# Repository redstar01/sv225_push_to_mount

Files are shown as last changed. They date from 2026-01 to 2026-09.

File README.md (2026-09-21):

# Проект модернизации альт-азимутальной монтировки телескопа Svbony sv225 до системы Push-To

🌐 **Русский** | [English](README.en.md)

DIY-проект: обычная ручная альт-азимутальная монтировка превращается в Push-To с привязкой к звёздам. ESP32 с двумя магнитными энкодерами MT6701 отдаёт положение осей в **Stellarium** (USB, протокол Meade LX200) или **SkySafari** (Bluetooth / Wi-Fi).

<p align="center">
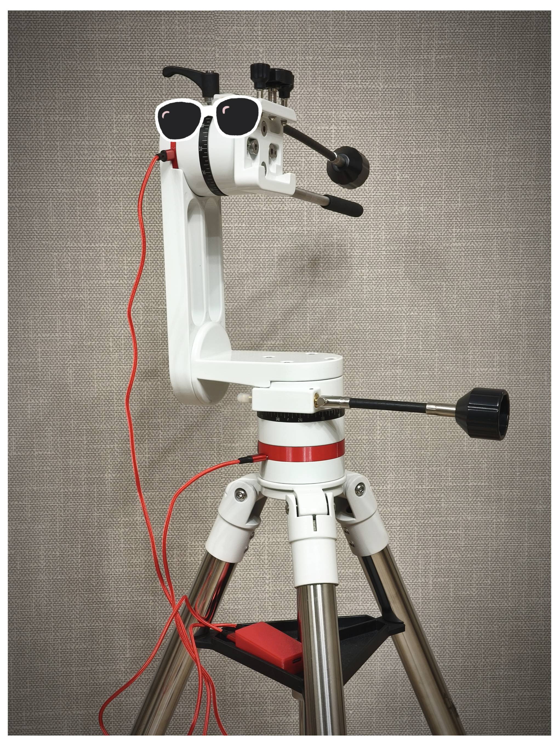
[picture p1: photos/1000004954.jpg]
    
</p>

## 🆕 Что нового: версия для Stellarium (beta)

Проект развивается в сторону **Stellarium** — эта версия уже приоритетная и рабочая (beta). Прошивки для SkySafari остаются стабильными и поддерживаются.

- **Подключение по USB** — не нужны Bluetooth, сопряжение и телефон: Stellarium видит ESP32 как монтировку Meade LX200.
- **Вся астрономия считается на ESP32** — звёздное время, прецессия J2000, перевод «углы осей ↔ RA/Dec».
- **Настройка с телефона по Wi-Fi** — страница `https://192.168.4.1/`: время UTC одной кнопкой, три слота места наблюдения с GPS, калибровка осей, живая таблица состояния.
- **Привязка к звёздам** (Sync из Stellarium) — до 6 точек, от 3 точек линейная модель по МНК; повторный Sync уточняет точку, а невязки и удаление — в веб-таблице.
- **Старт от полюса** — до первой привязки крест визирных нитей стоит у Полярной и следует за монтировкой.
- **Перевал через зенит** — координаты не «замирают»: прошивка отражает точку наведения, и крест продолжает двигаться.

<p align="center">
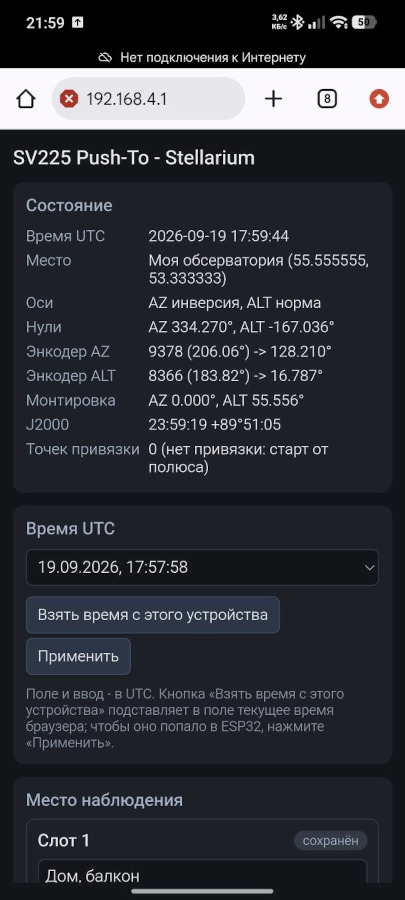
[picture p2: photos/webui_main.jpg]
    
    <br/>
    <em>Веб-интерфейс: состояние, время, слоты места и привязка — всё с телефона</em>
</p>

## 🚀 Обзор проекта

### Что такое Push-To?
Это система, которая показывает наблюдателю направление вращения ручек монтировки (после привязки к опорной звезде(-ам)), для наведения на любой звёздный объект.
Это значительно упрощает поиск тусклых галактик, туманностей и звёздных скоплений, невидимых невооруженным глазом.
А так же сильно помогает новичкам - астрономам для поиска объектов.

### Отличие от Go-To
В Go-To системе, монтировка сама наводится на объекты звездного неба за счет моторизированных приводов - это следующая ступень автоматизации и упрощения наведения.
В Push-To мы привязываемся к звездному небу и далее путем ручного вращения монтировки переходим от одной цели к другой, сопоставляя данные по наведению в программе-планетарии.

### Как это работает?
На осях монтировки устанавливаются датчики угла поворота (энкодеры).
Микроконтроллер ESP32 считывает их показания и передает данные в программу планетарий — та видит изменения положения осей и показывает, куда смотрит труба.
Для Stellarium пересчёт углов в координаты J2000 и модель привязки считаются прямо на ESP32.

## 📎 Функциональные возможности

### Stellarium — beta, приоритетное направление
- Протокол Meade LX200, подключение по USB (9600 8N1) — без Bluetooth и сопряжения.
- Координаты J2000; вся математика на ESP32: GMST/LST, прецессия (IAU 1976), alt-az ↔ RA/Dec.
- Привязка Sync: 1 точка — постоянные смещения, 2 — усреднение, 3+ — линейная модель (МНК), всего до 6 точек.
- Веб-интерфейс по Wi-Fi: время UTC, 3 слота места с названиями и GPS, калибровка осей (инверсия, нули), список привязок с невязками.
- Старт «от полюса» без привязки; перевал через зенит/надир не ломает наведение.
- Не нужны интернет и приложение на телефоне: USB-кабель и ПК со Stellarium.

### SkySafari — стабильные версии
- Протокол Basic Encoder System.
- Подключение по Bluetooth (удобно тем, что Wi-Fi остаётся свободным для интернета).
- Подключение по Wi-Fi (опционально, необходимо заливать отдельную прошивку).

## 💻 Программное обеспечение

Проект написан на C++/Arduino для платформы ESP32. Исходные коды [здесь](./src).

| Прошивка | Планетарий | Подключение | Статус |
|---|---|---|---|
| [stellarium_firmware.ino](./src/stellarium_firmware.ino) | Stellarium | USB (LX200) + веб-настройка по Wi-Fi | beta, приоритет |
| [bluetooth_firmware.ino](./src/bluetooth_firmware.ino) | SkySafari | Bluetooth | стабильно |
| [wifi_firmware.ino](./src/wifi_firmware.ino) | SkySafari | Wi-Fi | стабильно |

Инструкции: [подключение Stellarium](./tutorials/stellarium_connection.md) · [подключение SkySafari](./tutorials/skysafari_connection.md)

## 🎯 Как пользоваться

### Stellarium
Подробная инструкция — [tutorials/stellarium_connection.md](./tutorials/stellarium_connection.md).

1. Прошейте [stellarium_firmware.ino](./src/stellarium_firmware.ino): плата **ESP32 Dev Module**, схема разделов — стандартная (или «Huge APP (3MB No OTA/1MB SPIFFS)» для запаса).
2. Подключите ESP32 к ПК по USB. В Stellarium: плагин **Telescope Control** → «LX200 (compatible)» → «Послед. порт» → равноденствие **J2000**.
3. Задайте время и место: Wi-Fi **`redstar01`** (пароль `1234567890`) → `https://192.168.4.1/` (браузер один раз предупредит о самоподписанном сертификате). Кнопка «Взять время с этого устройства» → «Применить»; в слоте места — «Взять GPS» → «Использовать».
4. Наведите монтировку на звезду, выберите её в Stellarium и нажмите **`Ctrl+Shift+1`** (Sync). Повторите для 2–3 звёзд, разнесённых по небу.
5. Вращайте ручки — крест визирных нитей двигается по небу. Выберите объект и подводите трубу вручную.

До первой привязки крест стоит на полюсе мира (рядом с Полярной) и следует за монтировкой: первый Sync заменяет эту грубую модель точной.
Время и координаты должны совпадать со Stellarium: 1 минута расхождения времени — это 15′ промаха у небесного экватора.
Если веб-интерфейс недоступен, те же параметры задаются командами по serial: `T 2026-09-17 18:00:00`, `SLOT 1 55.0583 73.2950 Дача`, `SLOTUSE 1` (`HELP` — список команд).

### SkySafari
Подробная инструкция — [tutorials/skysafari_connection.md](./tutorials/skysafari_connection.md).

1. Подключаем питание через usb (для devkit платы) к esp 32.
2. Прошиваем `bluetooth_firmware.ino` (или `wifi_firmware.ino`) и на устройстве с SkySafari подключаемся к bluetooth(wifi) esp 32.
3. [В SkySafari делаем коннект к предварительно настроенному телескопу.](./tutorials/skysafari_connection.md) (число шагов энкодеров `-16383`).
4. Делаем привязку к опорным звездам, желательно от 3 шт, но сносно будет работать и по 1 звезде. (если поле зрения телескопа не велико, то искомый объект всегда попадет в окуляр).
5. Вращаем ручки монтировки, видим движение направления телескопа в SkySafari. Далее выбираем любой объект в программе и подводим телескоп к нужной цели.

## ⚙️ Компоненты и материалы
- Микроконтроллер ESP32 DevKit (1 шт)
- Абсолютные магнитные энкодеры MT6701 (2 шт)
- Увеличенные магниты для энкодеров (опционально, позволят увеличить точность) (2 шт)
- USB-C порты (4 шт) 
- Удлиненные болты в дюймовой системе, размер 1/4-20, длинна 1-1/8" (6 шт)
- Подшипник игольчатый 6*19 (2шт)
- Смазка ЦИАТИМ-F
- 3D печатные детали

## 🔧 Cборка
Подробная инструкция по сборке [здесь](./tutorials/assembly.md)

## 🖨️ 3D модели

Все модели для печати можно найти [здесь](./models/STL)

## 📷 Фото

Фото процесса сборки и конечный результат можно найти [здесь](./photos)

## 📞 Связаться с автором

GitHub: https://github.com/redstar01/sv225_push_to_mount

Telegram: https://t.me/redstar01 (Павел Красноперов)

## Отказ от ответственности
Вся информация предоставляется «как есть», без любых гарантий. Автор не несет ответственности за любой ущерб, повреждение оборудования, травмы или иные проблемы, возникшие в результате использования данной информации. Вы действуете на свой страх и риск.

## ❤️️ P.S. Если вам понравился проект, поставьте звезду на GitHub!

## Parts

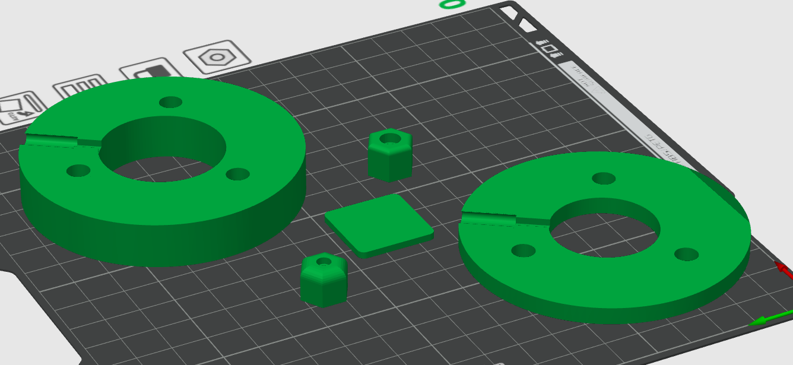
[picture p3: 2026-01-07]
models/STL/parts/preview.png

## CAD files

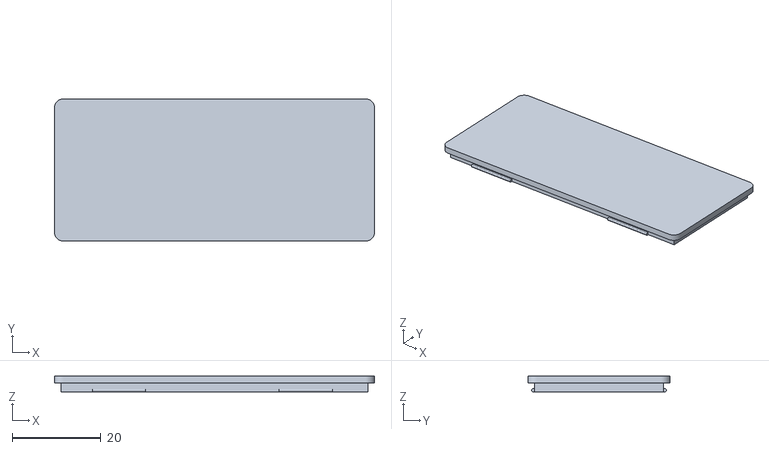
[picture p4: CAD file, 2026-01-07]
models/STL/body/body-top.stl
72.0 x 32.0 x 3.50

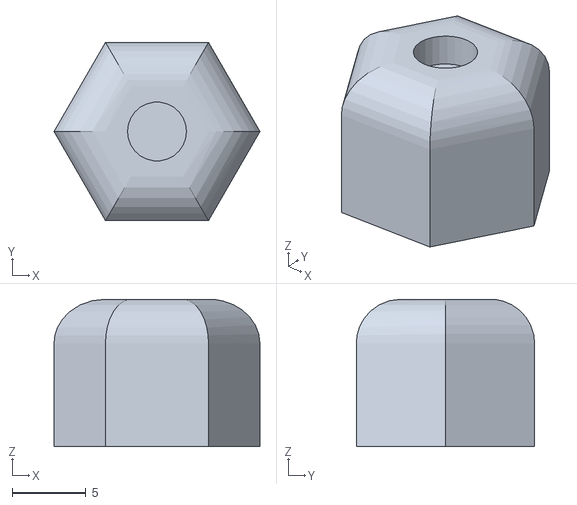
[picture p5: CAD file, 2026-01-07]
models/STL/parts/magnet_holder_default.stl.stl
14.0 x 12.1 x 10.0

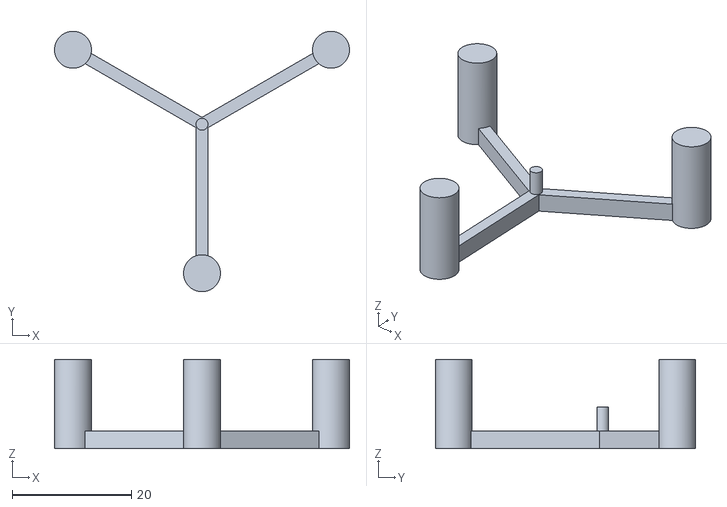
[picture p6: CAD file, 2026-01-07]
models/STL/pattern/template_for_mounting.stl
49.5 x 43.7 x 15.0

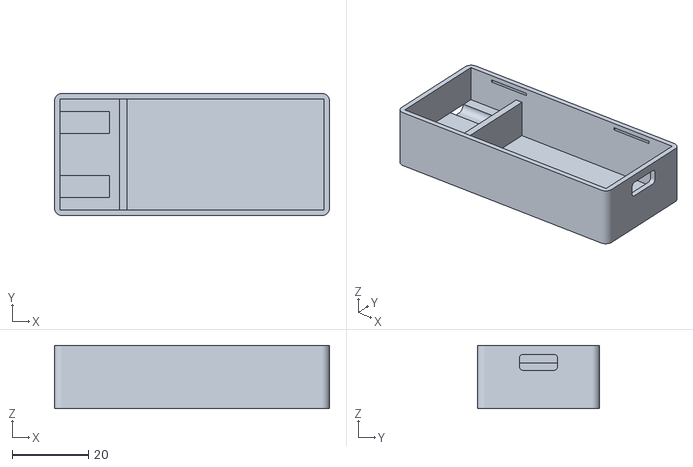
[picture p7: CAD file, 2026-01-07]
models/STL/body/body.stl
72.0 x 32.0 x 16.5

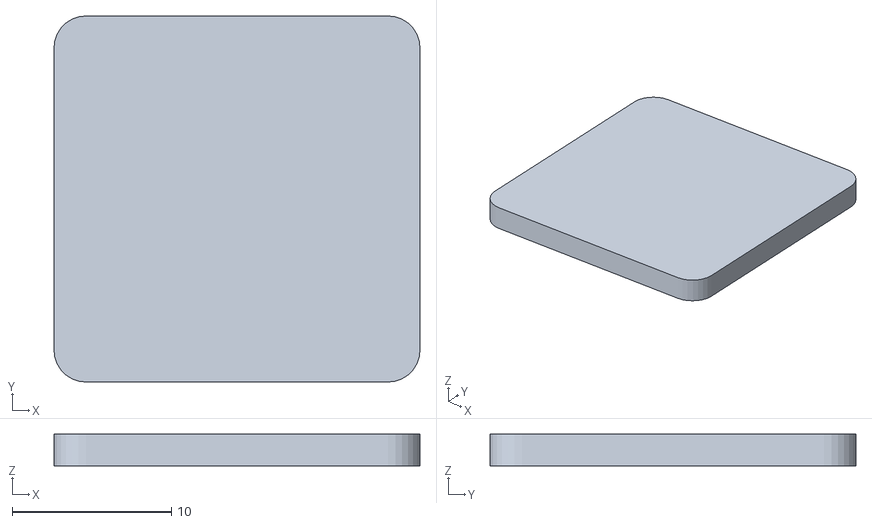
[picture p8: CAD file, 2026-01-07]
models/STL/parts/pcb_spacer_2mm.stl
23.0 x 23.0 x 2.00

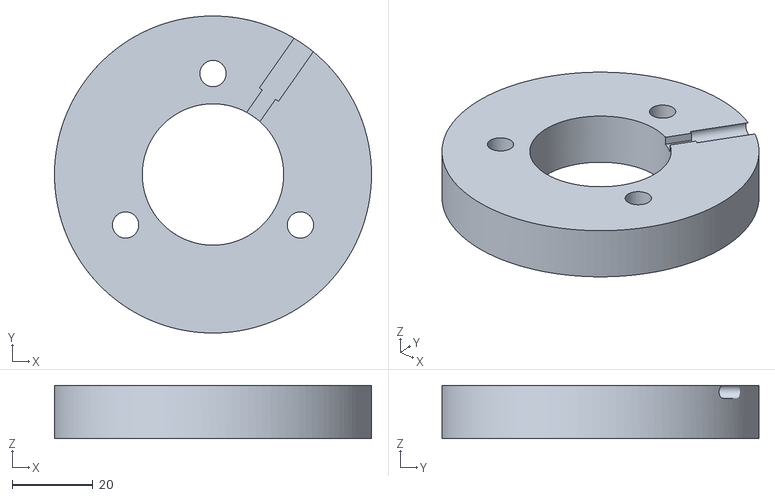
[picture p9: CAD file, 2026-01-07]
models/STL/parts/azm_spacer.stl.stl
78.5 x 78.5 x 13.2

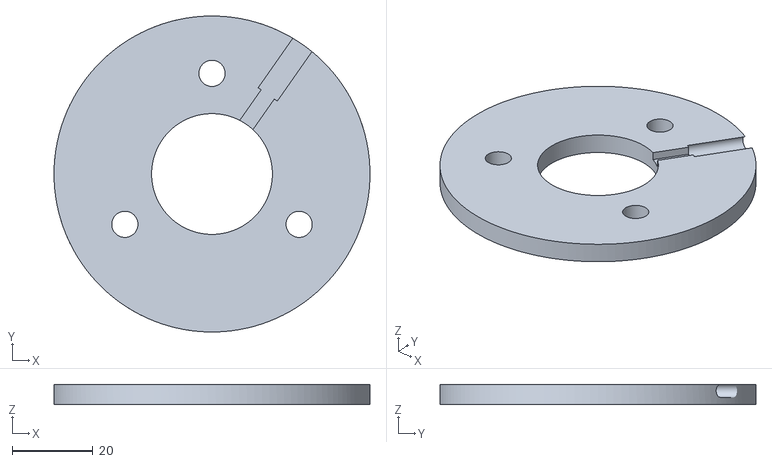
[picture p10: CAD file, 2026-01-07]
models/STL/parts/alt_spacer.stl
78.5 x 78.5 x 5.00

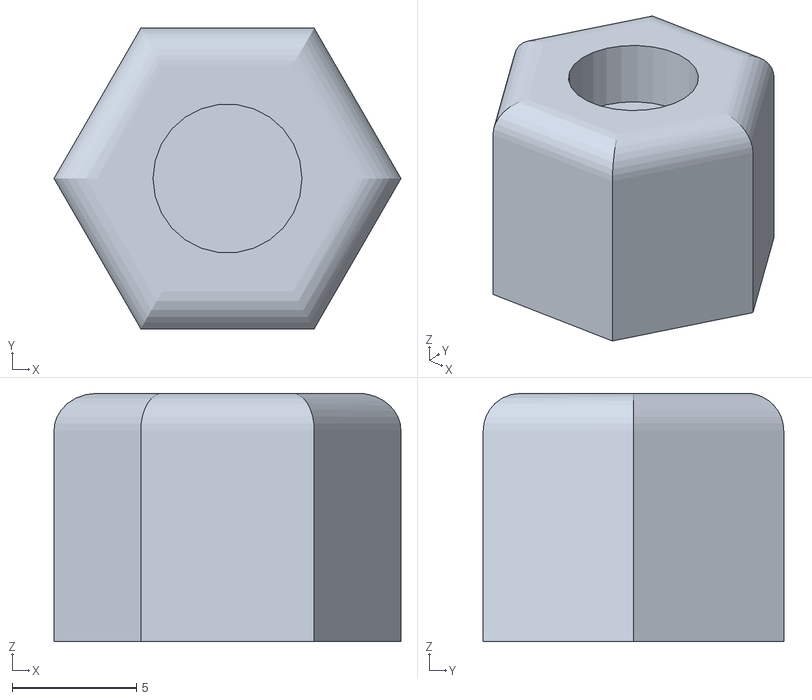
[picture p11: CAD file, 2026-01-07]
models/STL/parts/magnet_holder_big_6mm.stl
14.0 x 12.1 x 10.0

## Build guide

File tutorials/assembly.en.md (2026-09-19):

# Guide to upgrading the Svbony SV225 alt-azimuth mount to Push-To

🌐 [Русский](assembly.md) | **English**

## Preparatory work
Before upgrading the mount, its mechanics should be brought to the best possible condition; in my case I replaced the grease and got rid of the play by adding a thrust bearing.

### Grease replacement
Before assembly proper, the factory grease must be completely replaced, because from the factory it stiffens badly in the cold even at slightly below zero temperatures.
The recommended grease is CIATIM-F (ЦИАТИМ-Ф) — the cheapest of the analogs and it has no meaningful effect on the aluminum the mount is made of.

<div style="text-align: center;">
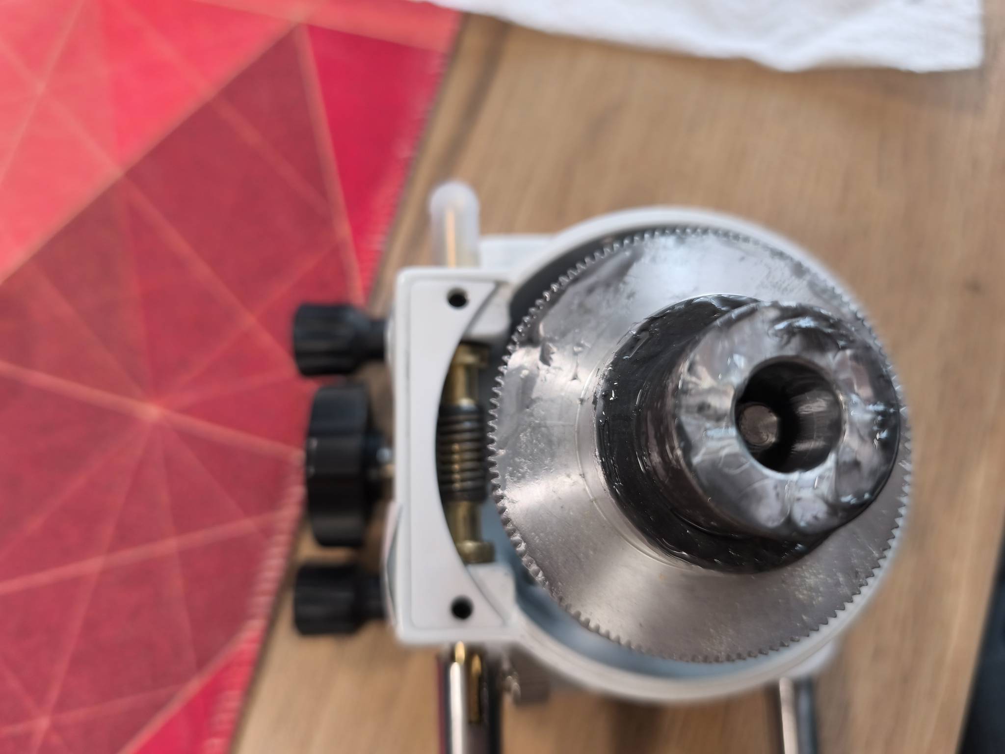
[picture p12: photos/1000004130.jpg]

<p><em>Removing the old silicone-based grease:</em></p>
</div>

<div style="text-align: center;">
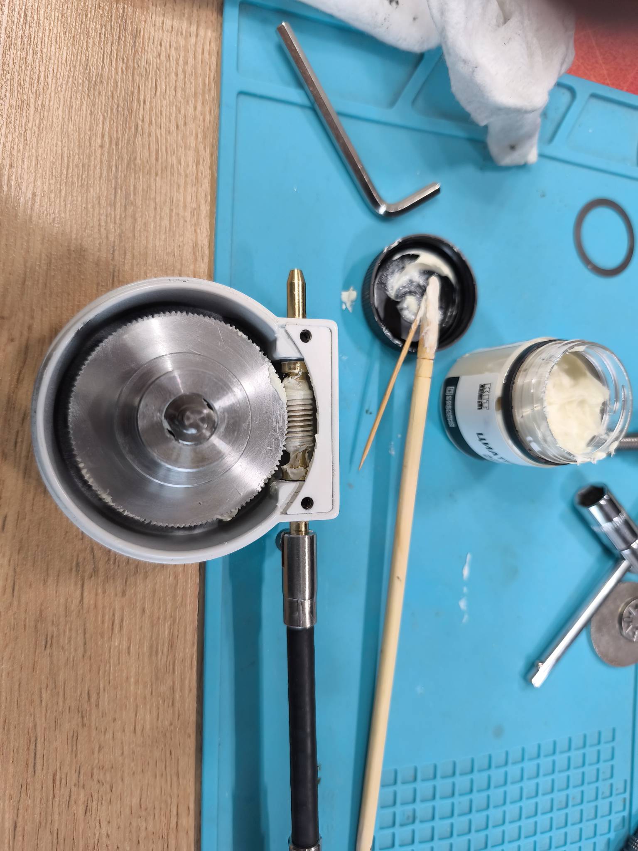
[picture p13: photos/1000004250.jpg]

<p><em>Applying aviation grease CIATIM-F:</em></p>
</div>

### Eliminating play
The play was eliminated by adding a 6*19 needle thrust bearing (2 mm thick) under the self-locking nut. The gap is adjusted experimentally so that the mount rotates freely enough while parasitic play is absent.

This upgrade requires no more serious mechanical modification of the mount.
The thread length is enough to tighten the nut, but for that the stock black and metal washers (which were right under the nut) must be removed and replaced with the bearing and the washer from the bearing kit.

The bearing kit includes 2 washers, but only 1 should be installed, since on the opposite side the bearing rests on the surface of the mount's factory "thick" washer.

The worm gear pairs should also be adjusted. The process is rather painstaking and requires some skill and experience. Since it does not affect pointing accuracy, if you have never done this procedure before, it is better to leave it alone.

<div style="text-align: center;">
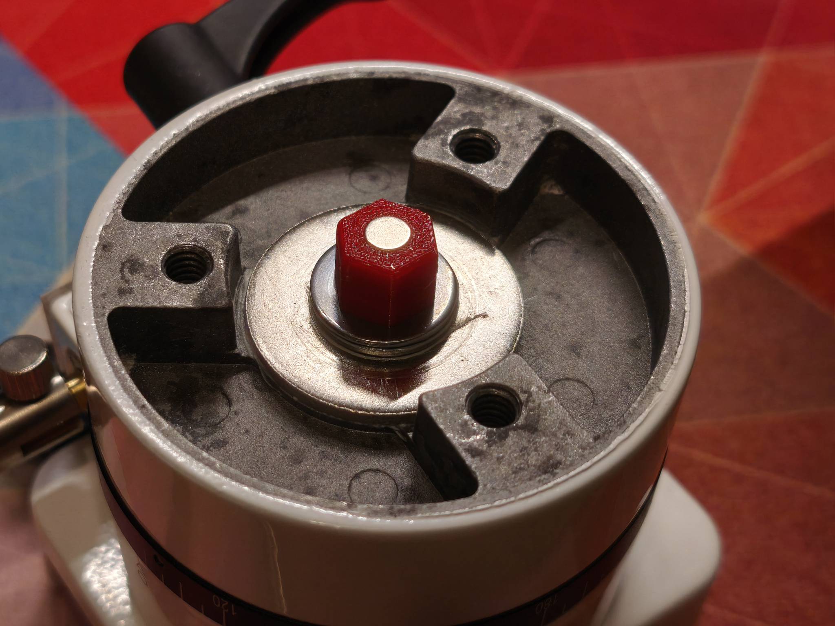
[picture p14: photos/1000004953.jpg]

<p><em>This photo shows the resulting "sandwich" (bottom to top: the thick washer from the mount, the needle thrust bearing, the washer from the bearing kit, the nut, and the magnet holder)</em></p>
</div>

## Upgrade

The main idea of the upgrade is to add magnetic encoders to the mount and read their values. The higher the encoder resolution, the more precisely you can point at objects.

Considering that this SV225 mount is used mostly for visual astronomy, and also taking into account the cost of encoders, I settled on MT6701 magnetic encoders. Their accuracy is 16,384 steps per full revolution, or 0.02 degrees.
The price as of 2025 is 100 rubles apiece (or $1). Theoretically various other encoders can be used, but the firmware would need to be modified.

It is better to buy the encoders mounted on a board, with the included magnet. These use special, rather rare radially magnetized magnets. Sourcing them separately is quite difficult.
The kit usually includes a 4 mm magnet, which is a workable option, but I found 6 mm magnets sold separately; the project has models for both variants.
A larger diameter should give better accuracy.

A gap of about 1–1.5 mm must be set between the magnet and the encoder sensor; for this the spacer washers were designed with a margin for possible adjustment (slightly larger).
To adjust the gap, shims of the required thickness are placed under the encoder board. The project contains a model 2 mm thick. You need to edit the thickness for your gap.

## 3D printing

Print the models:
- [Mount parts](../models/STL/parts)
- [Body](../models/STL/body)
- [Template for installing the encoder board](../models/STL/pattern)

PETG plastic with 15–20% infill was used for printing the parts. No problems with the mount's rigidity were noticed.

## Assembly

First, unscrew the 6 screws in the pictures below.

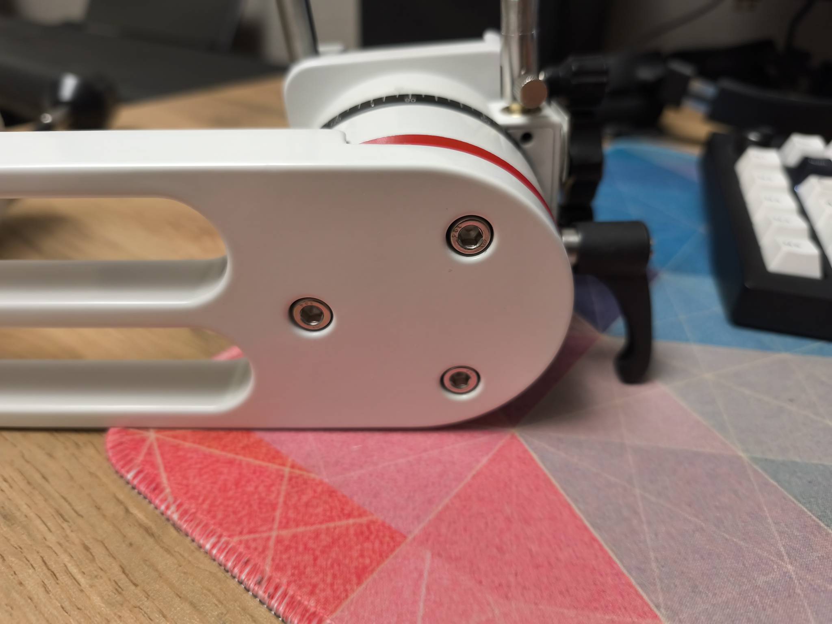
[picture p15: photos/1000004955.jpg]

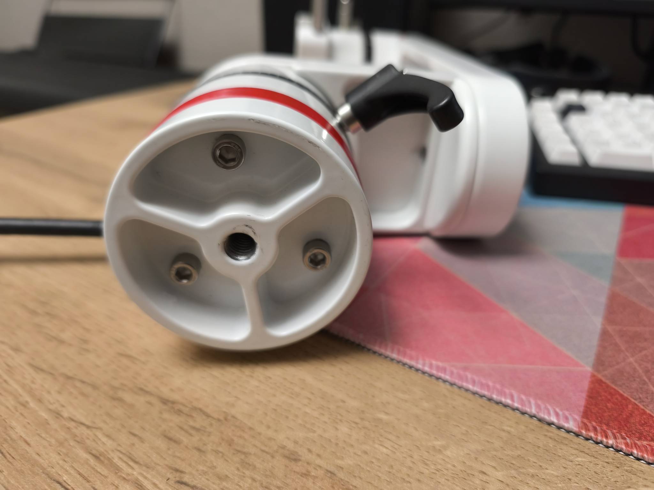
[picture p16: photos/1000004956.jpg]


<div style="text-align: center;">
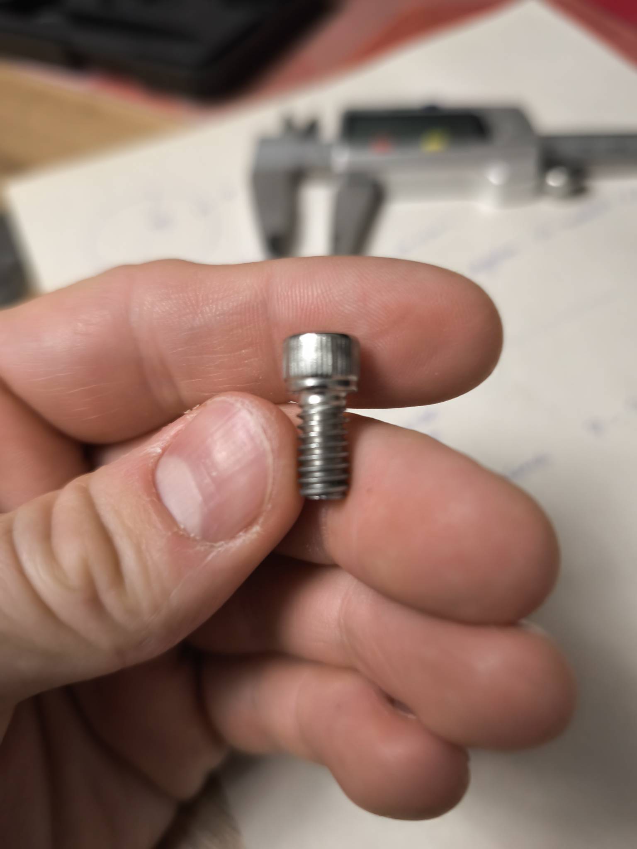
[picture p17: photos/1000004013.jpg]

<p><em>Unscrewed bolts</em></p>
</div>

<div style="text-align: center;">
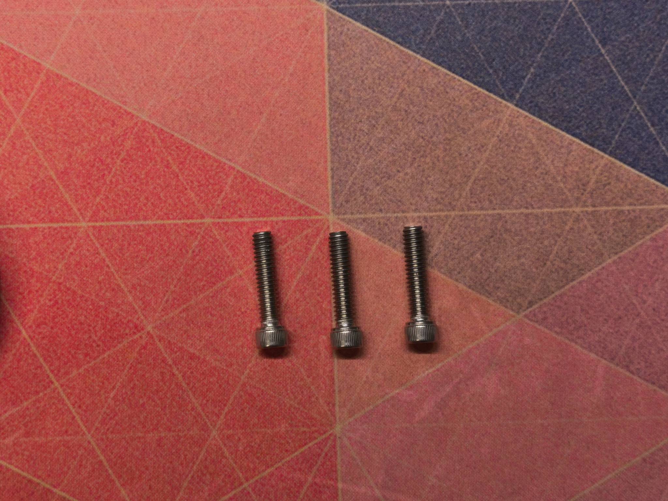
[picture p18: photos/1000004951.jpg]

<p><em>After the upgrade, longer bolts of size 1/4-20, length 1-1/8" must be installed (imperial system! I could only find them made to order on AliExpress)
</em></p>
</div>

Next we install the magnet holders (together with the magnets) on the nuts that lock the shafts:

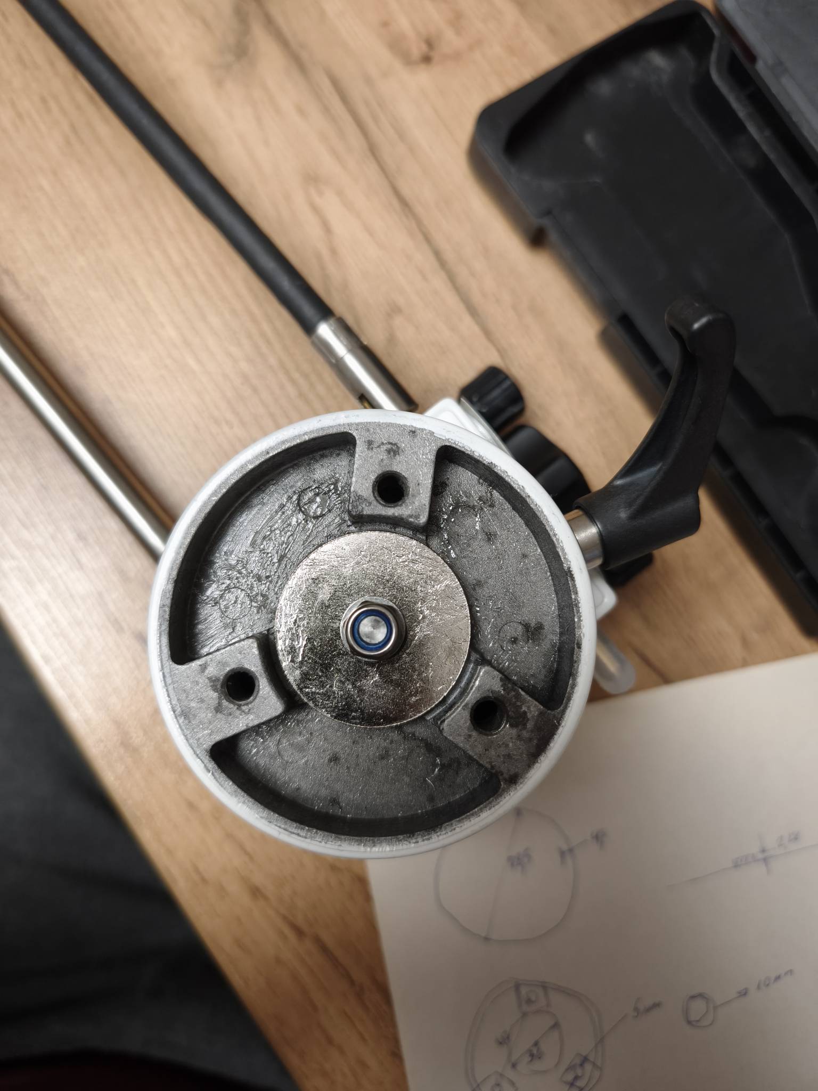
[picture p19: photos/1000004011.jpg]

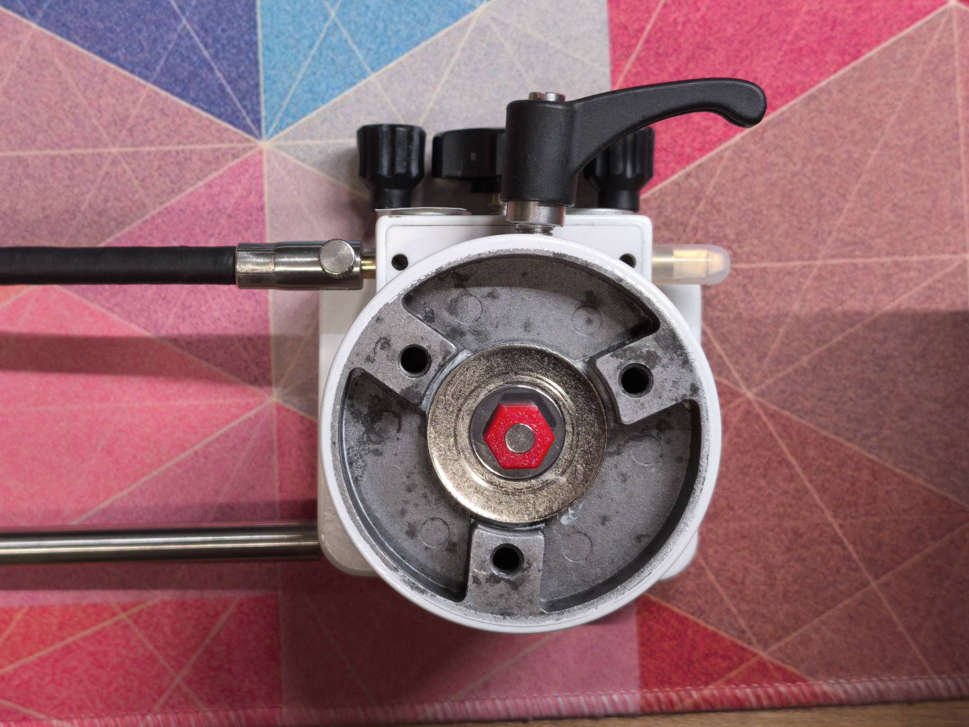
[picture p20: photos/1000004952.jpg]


To position the encoder precisely relative to the magnet, print the [3D template](../models/STL/pattern).
It helps install the encoder exactly centered relative to the shaft. The template must be inserted into the bolt holes; the central pin marks the point for installing the encoder.

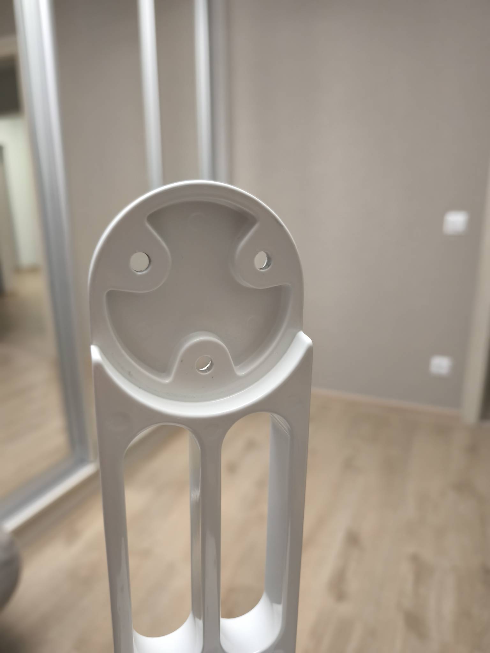
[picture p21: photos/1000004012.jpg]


<div style="text-align: center;">
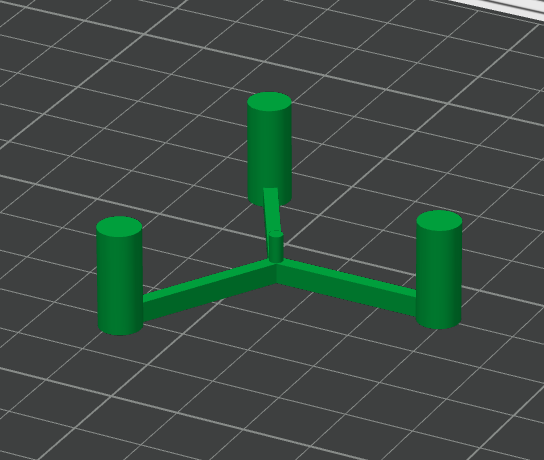
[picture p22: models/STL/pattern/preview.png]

<p><em>Template for precise encoder installation</em></p>
</div>

We install the encoder boards (with glue), having first measured the distance from the magnet to the encoder; the distance must be made up with shims (ideally it should be 1–1.5 mm).

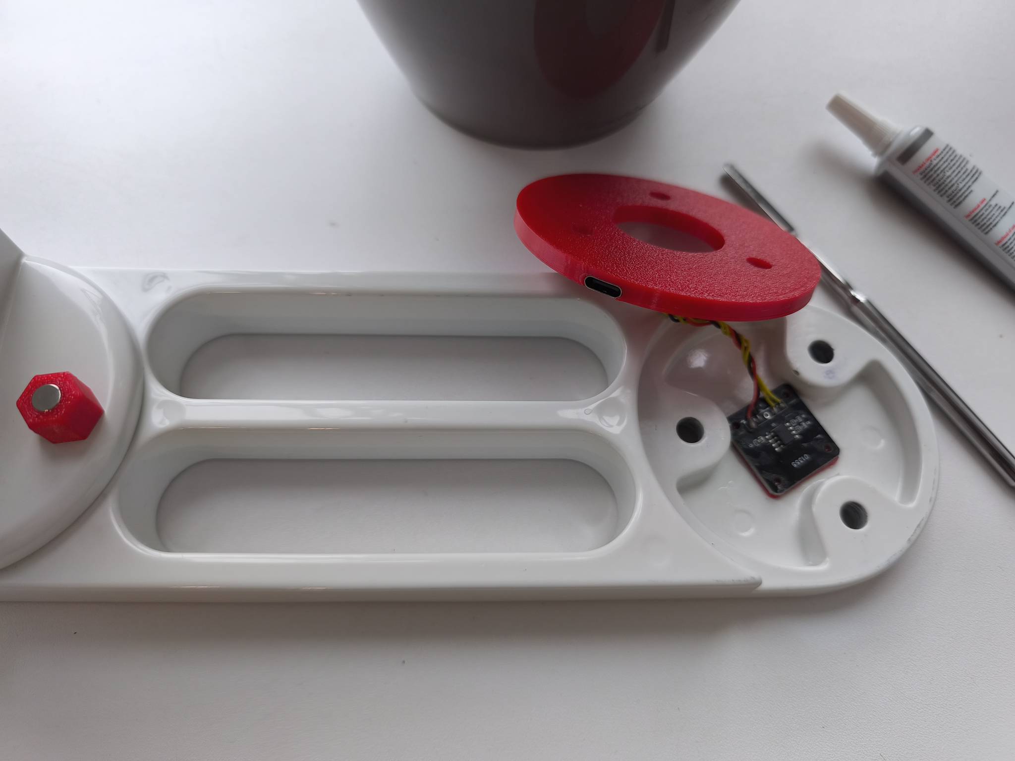
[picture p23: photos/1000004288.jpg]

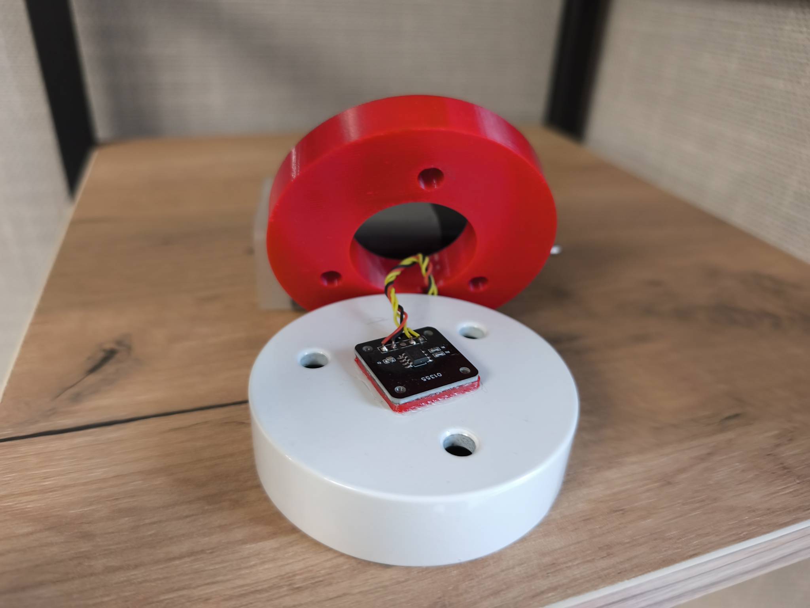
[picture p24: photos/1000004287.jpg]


We install the USB-C connectors into the slots on the spacer washers and connect them to the board with silicone wires.
4 wires in total: 2 for power, 2 for the I2C bus data.

<div style="text-align: center;">
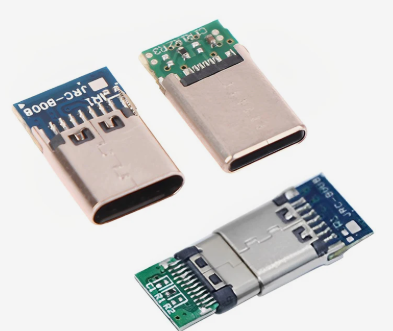
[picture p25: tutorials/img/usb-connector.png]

<p><em>Connectors of this type must be installed</em></p>
</div>

Assemble the mount; the final result:

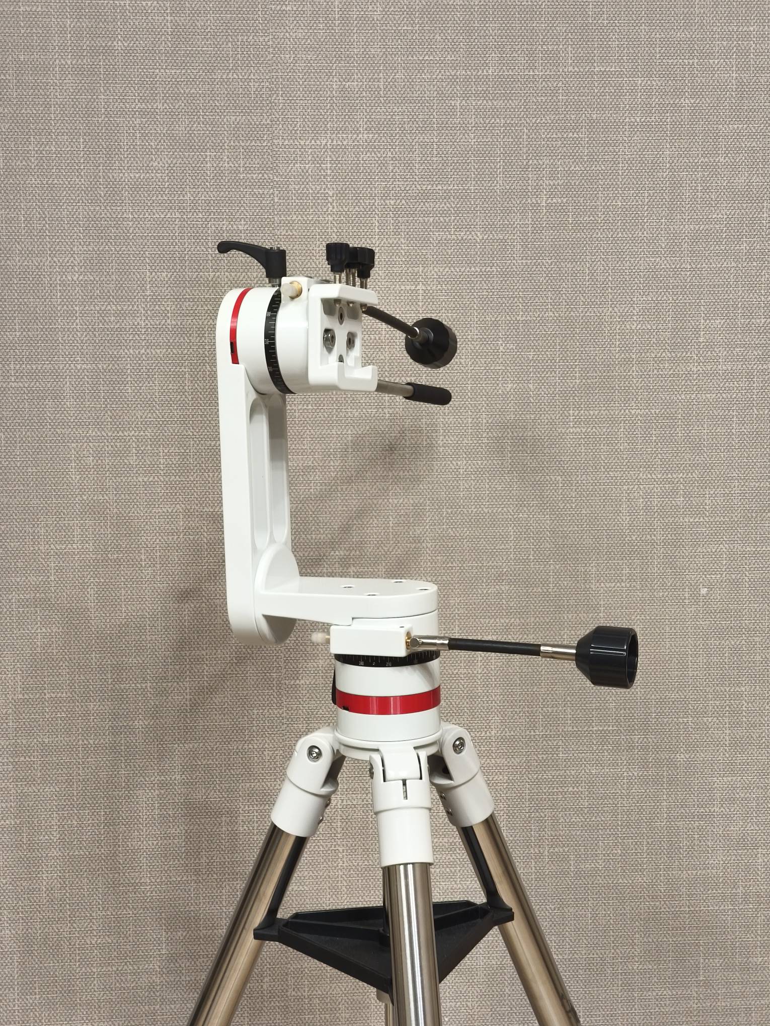
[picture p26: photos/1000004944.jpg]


## Flashing the firmware

The repository contains three firmwares: [stellarium_firmware.ino](../src/stellarium_firmware.ino) (Stellarium, USB),
[bluetooth_firmware.ino](../src/bluetooth_firmware.ino) and [wifi_firmware.ino](../src/wifi_firmware.ino) (SkySafari).
The procedure is fairly standard; if I find the time I will describe it in more detail later.

## ESP32 ↔ MT6701 wiring diagram

<div style="text-align: center;">
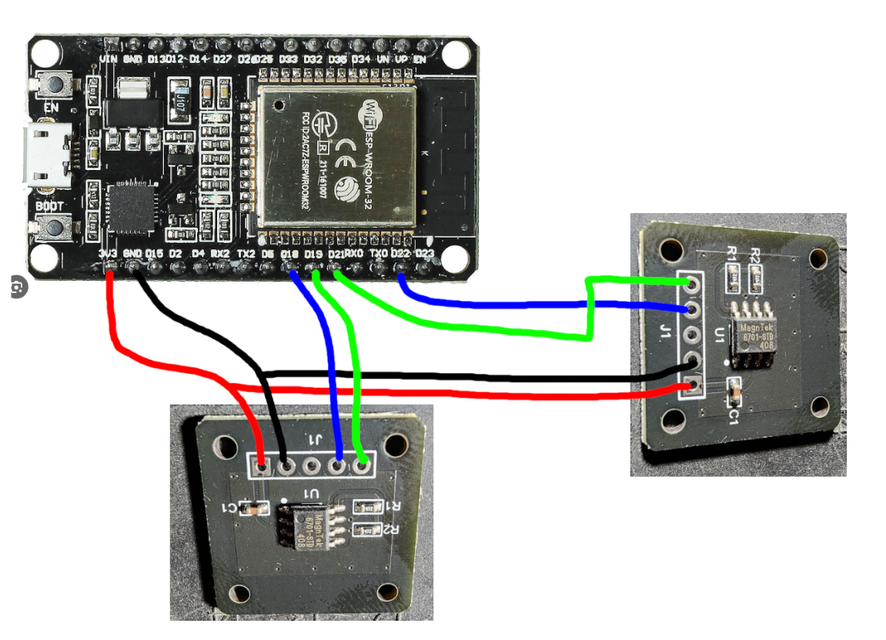
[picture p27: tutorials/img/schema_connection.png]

<p><em>Wiring diagram of the ESP32 dev kit board with two MT6701 encoders</em></p>
</div>

Two I2C buses are used because these sensors have a fixed address that cannot be changed.

## ESP32 enclosure

In the minimal version you can do without an enclosure by assembling everything on a breadboard or free-form.

For those who want to build it like the author, print the [enclosure](../models/STL/body) and install the USB-C connectors in it.
Then connect the ESP32 and the connectors with silicone wires.

The mount and the board in its enclosure are connected to each other with any USB-C to USB-C cables.

## P.S.

Many moments could not be captured, much has been forgotten. But the general details from this guide should shed light on the main idea.

Always happy to get feedback, ask questions at https://t.me/redstar01

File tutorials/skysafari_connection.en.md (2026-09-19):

# Connecting the mount to SkySafari

🌐 [Русский](skysafari_connection.md) | **English**

In the SkySafari settings you need to add a telescope using the Basic Encoder System protocol. Then follow the steps in the screenshots below.

<div style="text-align: center;">
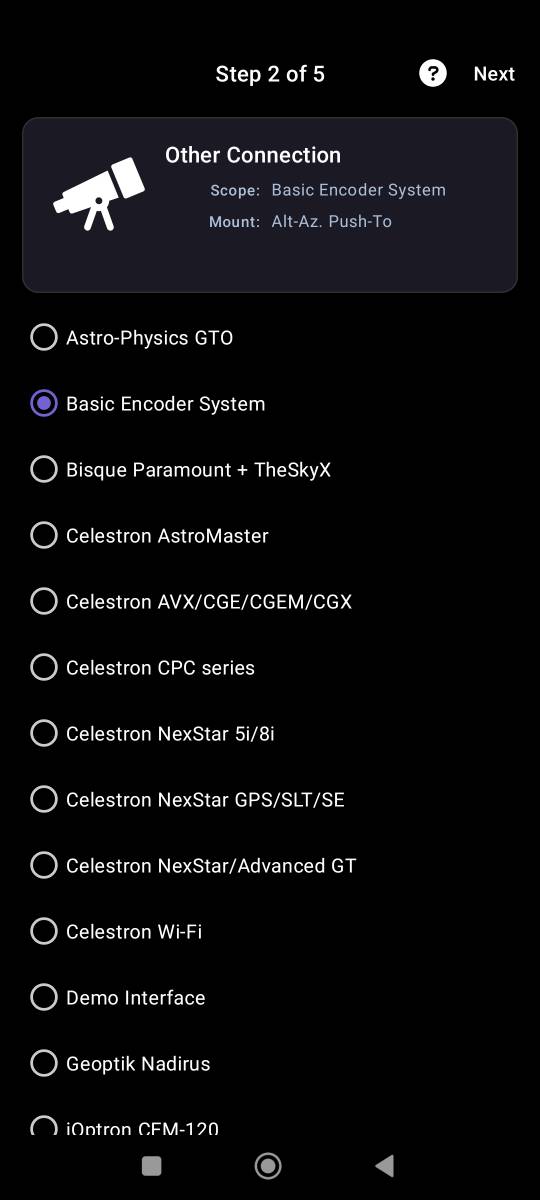
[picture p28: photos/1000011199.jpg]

<p><em>Select the Basic Encoder System protocol</em></p>
</div>

<div style="text-align: center;">
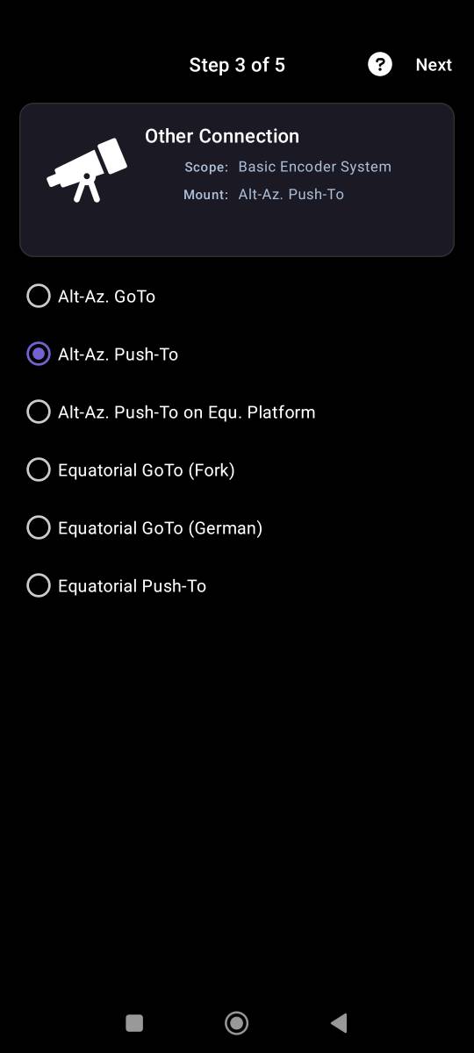
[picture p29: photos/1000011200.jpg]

<p><em>Mount type Alt-Az. Push-To</em></p>
</div>

<div style="text-align: center;">
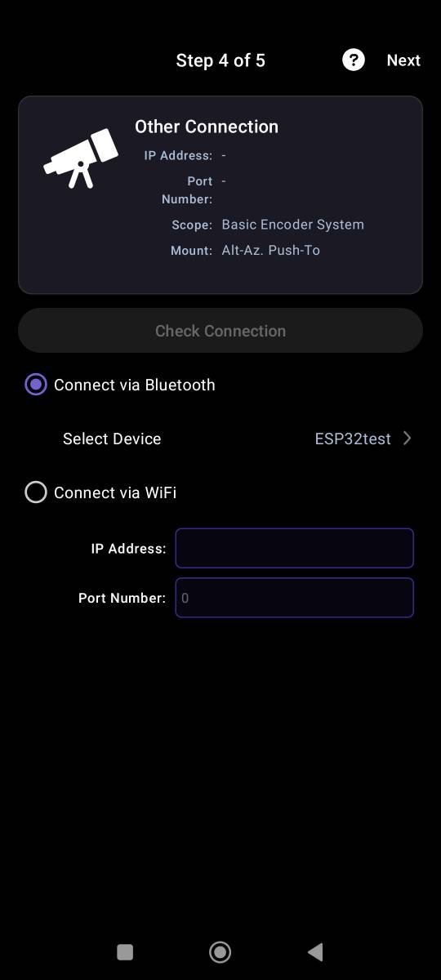
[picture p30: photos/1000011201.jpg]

<p><em>Choose the connection type depending on the firmware flashed. For Wi-Fi: ip: 192.168.4.1, port: 80</em></p>
</div>

<div style="text-align: center;">
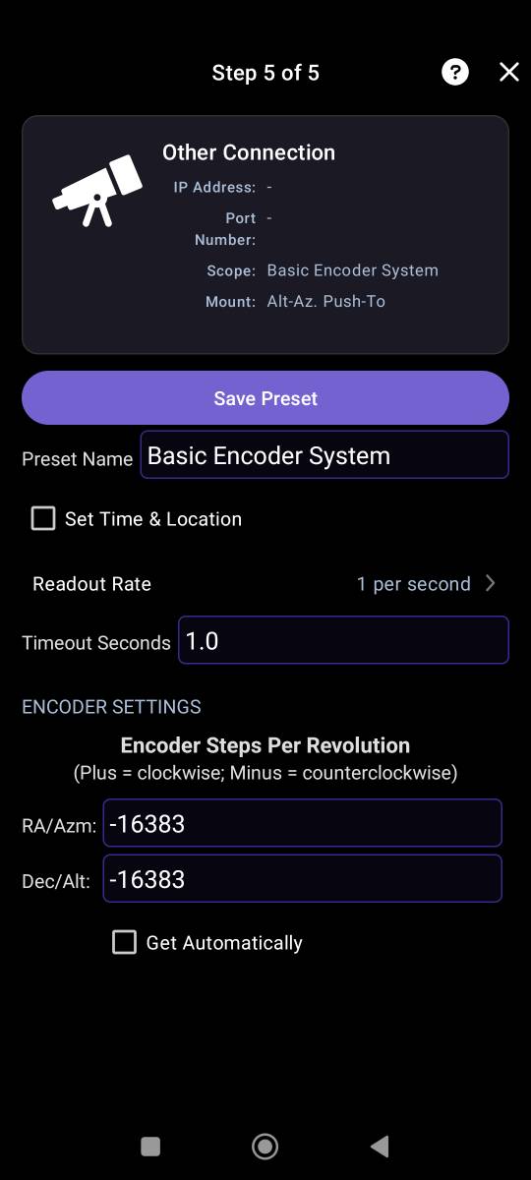
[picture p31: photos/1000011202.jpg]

<p><em>Specify the encoder step count, -16383 (with a minus sign)</em></p>
</div>

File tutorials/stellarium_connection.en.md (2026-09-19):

# Connecting the mount to Stellarium (LX200 protocol)

🌐 [Русский](stellarium_connection.md) | **English**

A separate firmware is used for Stellarium: [`src/stellarium_firmware.ino`](../src/stellarium_firmware.ino).
Stellarium sees the ESP32 as a **Meade LX200 (compatible)** mount; the link is over USB (serial, 9600 8N1).
All the math (converting encoder angles to RA/Dec) and the alignment model are computed on the ESP32.
The easiest way to set the parameters is through the web interface over Wi-Fi (the ESP32 brings up its own
access point); text commands over serial also work.

## 1. Flashing

- Arduino IDE → board **ESP32 Dev Module** → open `stellarium_firmware.ino` → upload.
- Partition scheme: the default one will do — the sketch takes ~82% of it.
  If you plan further development, select **"Huge APP (3MB No OTA/1MB SPIFFS)"** ("Tools →
  Partition Scheme") — it leaves headroom. After changing the partition scheme, check on the settings page
  that the saved site slots and axis settings are still there.
- The USB port in the firmware runs at **9600 baud** (Stellarium opens it at that speed),
  so open the "Serial Monitor" at 9600 too.

## 2. Setup via the web interface (Wi-Fi)

On power-up the ESP32 brings up its own Wi-Fi access point:

- network **`redstar01`**, password **`1234567890`**;
- settings page: **https://192.168.4.1/** (self-signed certificate)

1. On your phone or laptop, connect to the `redstar01` network. Internet on that device
   will disappear (the ESP32 does not share internet) — this is normal, for the duration of the setup.
2. Open `https://192.168.4.1/` in a browser. The browser will warn once that the
   certificate is self-signed: in Chrome — "Advanced" → "Proceed", in other browsers —
   "Accept the risk"/"Continue". This is safe: the certificate is embedded in the firmware and is valid
   only in this network.
3. At the top of the page is the live state (time, site, encoder angles, RA/Dec), below are the forms.
   The page itself is in Russian; the original button and field labels are given here in «guillemets»:
   - **UTC time** («Время UTC») — a field for entering the time in UTC. The **"Take time from this
     device"** button («Взять время с этого устройства») puts the browser's current time (converted
     to UTC) into the field, after which press **"Apply"** («Применить») — only then does the time get
     into the ESP32;
   - **Location** («Место наблюдения») — **three site slots** (stored in the ESP32 memory).
     Each slot has: a name (optional), latitude and longitude (north/east `+`, south/west `-`),
     a **"Take GPS"** button («Взять GPS» — the coordinates are taken from the browser, i.e. a phone with GPS, and
     put into the slot's fields; on the first press allow location access),
     a **"Save"** button («Сохранить» — write the slot to memory) and a **"Use"** button
     («Использовать» — make the slot the current observation site). The current, i.e. active, slot
     is highlighted and marked "in use" («используется»); the "Clear" button («Очистить») resets the slot;
   - **Axes and encoder zeros** («Оси и нули энкодеров») — the "Invert AZM axis"/"Invert ALT axis"
     checkboxes («Инверсия оси AZM»/«Инверсия оси ALT» — equivalent to `AZDIR -1`/`ALTDIR -1`)
     and the `AZZERO`/`ALTZERO` zeros; the "AZ = 0 now" and "ALT = 0 now" buttons («AZ = 0 сейчас»,
     «ALT = 0 сейчас») make the current position the axis zero: press "ALT = 0 now" with the tube
     horizontal, "AZ = 0 now" with the tube pointing north (see §3 "Encoder zeros").
     Set the directions and zeros before alignment: after changing them the Sync points are wrong —
     press `CLEAR` and align again;
   - **Alignment** («Привязка») — a table of the saved Sync points (axis angles, true angles,
     residual) with a "Delete" button («Удалить») for each, a button to reset all points (`CLEAR`)
     and the text `STATUS`.

   Answers to commands are shown at the bottom of the page; everything is saved in the ESP32 memory in the same way as when entering commands over serial.

Wi-Fi and LX200 work simultaneously: Stellarium is connected over USB while the settings are being
set from the page. The device's Wi-Fi adapter connects to only one network, so while you work with the
page the laptop will have no internet (setting things up from a phone is more convenient).

If the enabled Wi-Fi is not needed, it can be turned off: at the beginning of `stellarium_firmware.ino`
replace `#define WEB_UI 1` with `#define WEB_UI 0` and reflash the board.

## 3. Time and observation site (serial commands)

If the web interface is unavailable, the same parameters are set with text commands.
Commands are entered as text terminated by a newline in the "Serial Monitor" (USB, 9600). While Stellarium
is using the port, you cannot enter commands into it — enter commands before connecting
Stellarium (the Wi-Fi page works at any time).

| Command | Example | Purpose |
|---|---|---|
| `T YYYY-MM-DD HH:MM:SS` | `T 2026-09-17 18:00:00` | **UTC** time |
| `SLOT <n> <lat> <lon> [name]` | `SLOT 1 55.0583 73.2950 Dacha` | save a site slot (n = 1..3) |
| `SLOTUSE <n>` | `SLOTUSE 1` | make the slot the current site |
| `SLOTCLEAR <n>` | `SLOTCLEAR 1` | clear the slot |
| `AZDIR 1` / `AZDIR -1` | `AZDIR -1` | azimuth axis direction |
| `ALTDIR 1` / `ALTDIR -1` | `ALTDIR 1` | altitude axis direction |
| `AZZERO <deg>` | `AZZERO -340` | azimuth encoder zero offset |
| `ALTZERO <deg>` | `ALTZERO -340` | altitude encoder zero offset |
| `STATUS` | `STATUS` | current state (including the alignment point list) |
| `PTDEL <n>` | `PTDEL 2` | delete alignment point number n (numbers as in `STATUS`) |
| `CLEAR` | `CLEAR` | reset alignment (Sync points) |
| `HELP` | `HELP` | command list |

The site is stored in three slots (`SLOT`/`SLOTUSE`/`SLOTCLEAR` commands or the buttons on the
web page), and the axis settings — all of this is saved in the ESP32 memory and persists after
a reboot: after power-up the active slot immediately becomes the current site.
The time must be set after every power-up (there is no RTC on the board; if the `T` command is not
set, the firmware compile time is used as an approximation).

Example of initial setup (enter one line at a time):

```
T 2026-09-17 18:00:00
SLOT 1 55.0583 73.2950 Dacha
SLOTUSE 1
STATUS
```

The latitude and longitude must match the location set in Stellarium
(settings window → "Location"), and the time must be UTC.

### Checking the axis directions

`STATUS` (and the "State" table, «Состояние», on the web page) shows three numbers for each axis.
Using azimuth as an example (the firmware prints in Russian; the translation is in brackets):

```
Энкодер AZ: raw 7456 (163.80°), после настройки: 163.800°
[AZ encoder: raw 7456 (163.80°), after setup: 163.800°]
```

- `raw 7456` — the "raw" encoder steps, 0…16383 per full revolution
  (1 step = 360/16384 ≈ 0.022° ≈ 1.3 arcminutes);
- `(163.80°)` — the same angle in degrees, still without direction and zero:
  `steps × 360 / 16384`;
- `после настройки: 163.800°` (after setup) — the axis angle in the mount's frame after `AZDIR`/`AZZERO`:
  `norm(direction × raw° + zero)`, where azimuth is normalized to 0…360° and altitude to −180…+180°.

This is still **not** the real azimuth or the real tube altitude — the real angles are shown by the
next line (`Углы монтировки` in `STATUS`, "Mount", «Монтировка», on the web page), already taking
alignment into account.

Rotate the mount:

- in azimuth **clockwise** (viewed from above) — the "after setup" azimuth should increase;
- tube **up** — the "after setup" altitude should increase.

If it increases the other way, set `AZDIR -1` and/or `ALTDIR -1`.

### Encoder zeros (AZZERO/ALTZERO)

The encoder is an absolute sensor within one revolution: it always outputs 0…16383 steps,
but where the "zero" of this revolution is depends only on how the magnet was installed
relative to the axis during assembly, and has nothing to do with the mount's mechanics. The
`AZZERO`/`ALTZERO` zeros shift the encoder scale so that its zero is in a convenient place; the values are stored
in the ESP32 memory.

**In what tube position to set the zeros:**

| Axis | Tube position | Action | Why |
|---|---|---|---|
| Altitude (ALT) | tube horizontal, looking at the horizon (check with a level) | "ALT = 0 now" button (or `ALTZERO`) | the tube's travel then lies around 0° and stays entirely in one half of the scale |
| Azimuth (AZ) | tube pointing north (e.g. at Polaris) | "AZ = 0 now" button (or `AZZERO`) | "after setup" is measured from north (convenient to read, does not affect accuracy) |

The buttons take axis inversion (`AZDIR`/`ALTDIR`) into account automatically. If you set the commands
manually, the sign depends on the direction: with `ALTDIR 1` it is `ALTZERO -<raw°>`, with
`ALTDIR -1` it is `ALTZERO +<raw°>` (the same for azimuth).

**Why this matters for altitude but hardly for azimuth.** A circular scale cannot be turned
into a number without a discontinuity: for azimuth it is at 0°/360°, for altitude at ±180°
(see "Checking the axis directions").

- For azimuth the discontinuity is harmless: azimuth is a circle, and the firmware always compares angles along the
  short arc. `AZZERO` is mostly for convenience.
- For altitude the discontinuity is dangerous: if it falls inside the tube's real travel, "after setup"
  jumps by 360° in the middle of the movement (e.g. `+179.9°` → `−179.9°`). Sync points on
  opposite sides of the discontinuity are seen by the model as ~360° apart, and the crosshair
  jumps or drifts away. Zeroing with the tube horizontal moves the travel 180° away from the discontinuity.

Usually the zeros can be left alone: the very first alignment (Sync) subtracts a constant offset.
Checking is easy: slowly sweep the tube through its entire real travel and watch the "after
setup" altitude — if there is no jump through ±180° anywhere, everything is fine.

Order: first `AZDIR`/`ALTDIR` and the zeros, then Sync. After changing a direction or a
zero, the old Sync points become invalid (they store the previous axis readings) —
do `CLEAR` and align again.

If the tube goes past vertical (crossing the zenith or nadir), the firmware reports the
coordinates folded: azimuth +180°, altitude 180°−altitude. This is the same point in the sky,
so the crosshair keeps moving instead of freezing at the zenith.

### Time and site accuracy

Time and site enter the calculations in the same way — only through sidereal time
`LST = GMST(UTC) + longitude`. If the LST in the ESP32 and Stellarium differ, the crosshair
is rotated around the celestial axis by that angle: **there is no error at Polaris**,
and toward the celestial equator it grows and reaches its maximum (outwardly it looks like "the crosshair
does not match the azimuth grid"). 1 second of time = 15 arcseconds of sky,
1 minute = 15 arcminutes, 1 hour = 15°; 1 arcminute of longitude equals 4 seconds of
time. A latitude error gives an offset of the same order as the error itself.

| Time discrepancy | Sky rotation | Error at the equator | Error at δ = 45° |
|---|---|---|---|
| 1 s | 15″ | 15″ | 11″ |
| 10 s | 2.5′ | 2.5′ | 1.8′ |
| 30 s | 7.5′ | 7.5′ | 5.3′ |
| 1 min | 15′ | 15′ | 10.6′ |
| 5 min | 1.25° | 1.25° | 53′ |
| 1 hour | 15° | 15° | 10.6° |

For visual observing, keep the pointing error at most ~1/3 of the eyepiece field of view.
Hence the permissible time discrepancy: a wide-field eyepiece (~2° field) — up to 2–3 minutes,
25 mm (~1.4°) — up to 1.5–2 minutes, 10 mm (~0.6°) — up to 40 seconds. A practical guideline is
**no more than 10 seconds**: that is an error of ≤2.5′ at the equator (none at Polaris) and less than one
encoder step (14 bits ≈ 1.3′); setting it more precisely is pointless.

- **Time** is easiest to take with the "Take time from this device" button (the phone's
  or laptop's clock is NTP-synchronized), then "Apply". If entering manually —
  UTC only: a timezone mistake is 15° per hour.
- The clock of the computer running Stellarium must also be synchronized (Linux:
  `timedatectl status` should show synchronization). The ESP32's and the
  computer's own drift over a night is fractions of a second and can be neglected.
- If the time in Stellarium is shifted manually or sped up, the ESP32 does not know about it:
  set the same moment with the `T` command (with accelerated time there will be no match in principle).
- **Longitude**: phone GPS (±10 m) has a margin of hundreds of times; even a 0.1° error
  (a few kilometers) gives ≤6′. Watch only the sign: east `+`, west `-` — a flipped
  sign turns the crosshair by tens of degrees.
- **Latitude**: an error gives roughly the same offset in altitude; GPS also has a margin here,
  and a map accurate to ~10 km gives ≤5′. Do not swap latitude and longitude.

Setup order: first the time (`T`), the active site slot (`SLOTUSE`) and the axis settings
(`AZDIR`/`ALTDIR`, zeros — see below), then Sync. Alignment points are computed from the current
time, site and axis readings: if you fix them after alignment, the model becomes
invalid — do `CLEAR` and align again.

## 4. USB connection

The port is detected automatically:

- **Windows**: after installing the CP210x or CH340 driver (depending on the board),
  `COMx` will appear in "Device Manager".
- **Linux**: `/dev/ttyUSB0` (or `/dev/ttyACM0`). The user must be in the `dialout` group
  (`sudo usermod -aG dialout $USER`, then log in again).
- **Linux, important**: the name `/dev/ttyUSBx` is not persistent — after replugging the board or a USB
  glitch the number can change (`ttyUSB0` → `ttyUSB1`), and Stellarium, having remembered the old path,
  stops connecting with the `cannot open serial device` error. Specify the stable path
  from `/dev/serial/by-id/` (it does not depend on enumeration order):
  ```
  ls /dev/serial/by-id/
  # usb-Silicon_Labs_CP2102_USB_to_UART_Bridge_Controller_0001-if00-port0
  ```
- **Stellarium from snap** (`stellarium-daily`, the snap name may differ): you need to allow USB-serial access once:
  ```
  sudo snap connect stellarium-daily:raw-usb
  ```

### Configuring the telescope in Stellarium

1. `F2` → **"Telescope Control"** plugin → "Configure"
   (or `Ctrl+1` — the "Telescopes" window).
2. "Add a new telescope".
3. "Telescope controlled by:" → **"Stellarium, directly (through serial port or network)"**.
4. "Device model:" → **LX200 (compatible)**.
5. "Connection:" → **"Serial port"** (not "Network (TCP)").
6. "Serial port:" → `COMx` / `/dev/ttyUSB0` (Linux: better a path from
   `/dev/serial/by-id/`, see §4).
7. "Equinox" → **J2000 (default)** — the firmware reports J2000 coordinates.
8. "Connection delay" — 0.5 s by default.
9. Save and press **"Connect"**.

After connecting, the telescope crosshair appears in the sky. Until any Sync has been made,
the crosshair sits at the celestial pole (next to Polaris) and moves together with the
mount's knobs: the firmware assumes that at power-up the tube was pointing at the pole.
If the mount is leveled and the tube was pointing at Polaris at power-up, you can
even point without alignment — the first Sync replaces this rough model with an exact one.

## 5. Star alignment

While there is no Sync point, the firmware assumes that at power-up (or after `CLEAR`)
the tube was pointing at the celestial pole: the crosshair sits next to Polaris and follows the mount.
The first Sync replaces this rough model. A convenient order: point the tube at Polaris and
make the first Sync on it, then refine the alignment with 1–2 stars in another part of the sky.

1. Make sure the time (UTC) and site in the ESP32 match the Stellarium settings
   (see §3 "Time and site accuracy").
2. Point the mount at a bright star and center it in the eyepiece.
   - Do the alignment while the tube is **below the zenith** (not folded over the top): the correction
     model measures altitude from the normal axis position, and a Sync on the fold will shift
     it for the whole sky.
3. Select that star in Stellarium (click on the star).
4. Press **`Ctrl+Shift+1`** — "Sync telescope #1 with the selected object"
   (in the "Slew" window these are the "Current object" → "Sync" buttons).
5. Repeat steps 2–4 for 2–3 stars spread across the sky (you can do more; up to
   6 points are stored).
   - 1 star — constant axis offsets;
   - 2 stars — the same offsets, averaged over the two points;
   - 3 or more stars — a linear error model (least squares over all stored points).
6. To point at an object, select it in Stellarium and press `Ctrl+1` — the crosshair
   shows the target, and you bring the tube to it manually by the difference in positions.
7. You can reset the alignment (e.g. after disassembling the mount) with the `CLEAR`
   command over serial or the button on the web page. After the reset the crosshair counts
   from the pole again, and the current tube position is taken as the pole.

A repeated Sync near an already aligned star (within ~5° in axis angles)
**updates** its point instead of adding an almost identical second one: if after pointing
the crosshair did not match the star, just point more precisely and press Sync again — this is
safe. When 6 points have been collected, a new Sync elsewhere replaces the oldest one.
`STATUS` and the "Alignment" table on the web page show the point list and the
residual (model error at each point); there you can delete a point with a button, or over
serial with the `PTDEL <number>` command.

Tip: after each Sync, check the accuracy on the same star — the crosshair
should coincide with the star. If it has drifted away, press Sync again.

## 6. Common problems

| Symptom | Cause/solution |
|---|---|
| Stellarium has no port in the list | Linux: no permissions (`dialout`), snap without `snap connect ...raw-usb`, a cable without data lines (charge-only) |
| Port busy / will not connect | The "Serial Monitor" is open (close it) or another program is using the port |
| After "Disconnect" it will not reconnect, the log shows `cannot open serial device` | The board re-enumerated under a different name (`/dev/ttyUSB0` → `/dev/ttyUSB1`) — specify a port from `/dev/serial/by-id/...` (see §4) |
| The page `https://192.168.4.1/` does not open | The device is not connected to the `redstar01` network (Wi-Fi is looking at another network); check that this exact firmware is flashed |
| The browser says "Connection not secure" / complains about the certificate | This is by design: the certificate is self-signed and valid only in this network. Click "Advanced" → "Proceed" (Chrome) or "Accept the risk" (other browsers) |
| No GPS coordinate request | Allow location access for the browser in the phone settings; on a computer without a GPS module the coordinates may be determined by Wi-Fi/network — that is inaccurate |
| The sketch will not compile: "Sketch too big" | The selected partition scheme is too small: take the default one or "Huge APP (3MB No OTA/1MB SPIFFS)" (see §1) |
| The crosshair twitches and "flies away" | No site slot selected (`SLOTUSE`) or no time set (`T`), or wrong axis directions (`AZDIR`/`ALTDIR`), or large alignment errors (see §3) |
| The crosshair jumps/drifts when the tube passes a certain place: `STATUS` shows the "after setup" altitude jumping ≈+180° → −180° | The altitude scale discontinuity fell inside the tube's travel: make the tube horizontal, press "ALT = 0 now" (or set `ALTZERO`), then `CLEAR` and Sync again (see §3 "Encoder zeros") |
| Alignment "broke" after changing `AZDIR`/`ALTDIR`/`AZZERO`/`ALTZERO` | The Sync points store the previous axis readings: do `CLEAR` and align again |
| The crosshair does not move | Wrong port selected; the SkySafari firmware is flashed (different protocol); Stellarium is set to "Network (TCP)" instead of "Serial port" |
| Large misses | UTC time not set (`T`), site mismatch (active slot coordinates), wrong `AZDIR`/`ALTDIR`, too few alignment stars or they are close to each other |
| The crosshair is rotated around Polaris: it matches near the pole but is far off toward the equator | Sidereal time mismatch: inaccurate time (`T`) or longitude (active slot); 1 minute of time = 15′ at the equator (see §3). If fixed after alignment — `CLEAR` and Sync again |
| The crosshair is offset in altitude by almost the same amount all over the sky | Wrong latitude (active slot) or alignment errors |
| Alignment lost after power-off | By design: Sync points are stored in RAM only; site slots and axis settings persist |

## 7. Notes

- Stellarium does not send either the time or the site coordinates to the mount — they must be set
  on the web page or with commands (`T`, `SLOT`/`SLOTUSE`).
- The web interface lives over Wi-Fi only: the ESP32's USB port is an ordinary serial port,
  a browser cannot open a page over it.
- While there are no alignment points, coordinates are counted from the celestial pole (see §5); this is not a "bug"
  and requires no setup — the first Sync switches the firmware to the normal model.
- GPS coordinates are taken from the device on which the page is open (a phone with GPS) and
  put into the slot fields (saving is done with the `SLOT` command): browsers provide geolocation
  only over HTTPS, which is why the page is served over HTTPS with a self-signed certificate.
  The device answers `http://192.168.4.1/` with a redirect to HTTPS.
- The firmware does not support an LX200 TCP connection (host:port) — use "Serial port"
  (USB).
- Refraction is not modeled; for push-to accuracy this is insignificant.

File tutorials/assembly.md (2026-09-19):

# Инструкция по доработке альт-азимутальной монтировки sv225 до PUSH-TO

🌐 **Русский** | [English](assembly.en.md)

## Предварительные работы
Перед модернизацией монтировки необходимо довести механику монтировки до возможного идеала, в моем случае я заменил смазку и избавился от люфтов путем добавления упорного подшипника.

### Замена смазки
Перед непосредственно сборкой, необходимо полностью заменить заводскую смазку, так как с завода она сильно дубеет на холоде уже при минимальных отрицательных значениях температуры.
Рекомендуемая смазка ЦИАТИМ-F - наиболее дешевая из аналогов и не оказывающая сколь-либо значимого влияния на алюминий из которого изготовлена монтировка.

<div style="text-align: center;">

<p><em>Снимаем старую смазку на силиконовой основе:</em></p>
</div>

<div style="text-align: center;">

<p><em>Смазываем авиационной смазкой ЦИАТИМ-F:</em></p>
</div>

### Устранение люфтов
Люфты получилось устранить путем добавления упорного игольчатого подшипника 6*19 (2мм толщина) под самоконтрящуюся гайку. Опытным путем устанавливается зазор, чтобы вращение монтировки было достаточно свободным, но в то же время отсутствовали паразитные люфты.

При данной модернизации не требуется какая-либо более серьезная механическая доработка монтировки. 
При этом хватает длины резьбы для затяжки гайки, но для этого необходимо убрать штатную черную и металлическую шайбу (которые были сразу под гайкой) и заменить на подшипник и шайбу из набора с подшипником.

В наборе с подшипником идет 2 шайбы, но установить необходимо только 1, так как с противоположной стороны подшипник будет опираться на поверхность заводской "толстой" шайбы монтировки.

Также стоит отрегулировать червячные пары. Процесс довольно кропотливый и требует определенной сноровки и опыта. Так как на точность позиционирования не влияет, если ранее не доводилось осуществлять данную процедуру, то лучше не трогать.

<div style="text-align: center;">

<p><em>На данном фото видно получившийся "бутерброд" (снизу-вверх: толстая шайба от монтировки, упорный игольчатый подшипник, шайба из комплекта подшипника, гайка, и держатель магнита)</em></p>
</div>

## Модернизация

Основная идея модернизации монтировки состоит в добавлении магнитных энкодеров в монтировку и считывании их показателей. Чем больше разрешение энкодера, тем точнее получится наводиться на объекты.

Учитывая, что данную монтировку sv225 используют в большей степени для визуальной астрономии, а также, беря во внимание стоимость энкодеров, я остановил свой выбор на магнитных энкодерах MT6701. Точность которых равна 16,384 шагов на полный оборот, или 0,02 градуса. 
Стоимость на 2025 год равна 100 рублей за шт (или 1$). Теоретически можно использовать различные другие энкодеры, но потребуется доработка программного кода.

Энкодеры лучше приобретать установленными на плате, с комплектным магнитом. Здесь используются специальные, довольно редкие магниты радиальной намагниченности. Достать их отдельно довольно сложно. 
В комплекте, как правило, находится магнит на 4мм, что является работоспособным вариантом, но я нашел в продаже отдельно магниты 6мм, в проекте есть модели под оба варианта.
С большим диаметром точность должна быть лучше.

Между магнитом и датчиком энкодера необходимо выставить зазор в районе 1-1.5мм, для этого шайбы-проставки были спроектированы с запасом под возможную регулировку (немного больше).
Для регулировки зазора под плату энкодера подставляются необходимой толщины подкладки. В проекте находится модель с толщиной 2мм. Требуется отредактировать толщину под ваш зазор.

## 3D печать

Распечатываем модели:
- [Детали монтировки](../models/STL/parts)
- [Корпус](../models/STL/body)
- [Шаблон для установки платы энкодера](../models/STL/pattern)

Для печати деталей использовался petg пластик с заполнением 15-20%. Каких-либо проблем с жесткостью монтировки замечено не было.

## Сборка

Первым делом откручиваем 6 винтов на рисунках ниже




<div style="text-align: center;">

<p><em>Выкрученные болты</em></p>
</div>

<div style="text-align: center;">

<p><em>После модернизации необходимо установить большей длины размер 1/4-20, длинна 1-1/8" (дюймовая система! Нашел только под заказ на али)
</em></p>
</div>

Далее устанавливаем держатели магнитов (вместе с магнитами) на гайки, которые фиксируют валы:




Для точного позиционирования энкодера относительно магнита необходимо распечатать  [3d шаблон](../models/STL/pattern). 
Он поможет установить энкодер ровно по центру относительно вала. Шаблон необходимо вставить в отверстия от болтов, центральный штырь укажет точку для установки энкодера.



<div style="text-align: center;">

<p><em>Шаблон для точной установки энкодера</em></p>
</div>

Устанавливем платы с энкодерами (на клей), предварительно измерив расстояние от магнита до энкодера, расстояние необходимо добрать подкладками. (в идеале должно быть 1-1.5 мм).




В пазы на шайбах-проставках устанавливаем USB-C коннекторы, силиконовыми проводами соединяем с платой.
Всего 4 провода, 2 - питание, 2 - данные I2C шины.

<div style="text-align: center;">

<p><em>Необходимо установить коннекторы данного типа</em></p>
</div>

Собираем монтировку, конечный результат:



## Заливка прошивки

В репозитории три прошивки: [stellarium_firmware.ino](../src/stellarium_firmware.ino) (Stellarium, USB),
[bluetooth_firmware.ino](../src/bluetooth_firmware.ino) и [wifi_firmware.ino](../src/wifi_firmware.ino) (SkySafari).
Процедура довольно стандартная, если появится время опишу ее подробнее позже.

## Схема соединения ESP32 c MT6701

<div style="text-align: center;">

<p><em>Схема соединения платы ESP32 dev kit с двумя энкодерами MT6701</em></p>
</div>

Используются 2 шины I2C, так как данные датчики имеют фиксированный адрес, который нельзя изменить.

## Корпус для ESP32

В минимальной версии можно обойтись без корпуса, собрав все на макетной плате или навесным методом.

Для тех, кто хочет сделать как у автора, распечатайте [корпус](../models/STL/body) и установите в него USB-C коннекторы.
Далее силиконовыми проводами соедините ESP32 и коннекторы.

Монтировка и сама плата в корпусе соединяются между собой любыми USB-C to USB-C кабелями.

## P.S.

Многие моменты не удалось зафиксировать, многое забылось. Но общие детали из данной инструкции должны пролить свет на главную идею.

Всегда рад обратной связи, задавайте вопросы https://t.me/redstar01

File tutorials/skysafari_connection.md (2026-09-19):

# Подключение монтировки к программе SkySafari

🌐 **Русский** | [English](skysafari_connection.en.md)

В настройках программы SkySafari необходимо добавить телескоп по протоколу Basic Encoder System. Далее идем по шагам из скринов ниже

<div style="text-align: center;">

<p><em>Выбираем протокол Basic Encoder System</em></p>
</div>

<div style="text-align: center;">

<p><em>Тип монтировки Alt-Az. Push-To</em></p>
</div>

<div style="text-align: center;">

<p><em>Выбираем в зависимости от залитой прошивки тип подключения. Для wifi: ip: 192.168.4.1, порт: 80</em></p>
</div>

<div style="text-align: center;">

<p><em>Указываем кол-во шагов энкодеров, -16383 (со знаком минус)</em></p>
</div>

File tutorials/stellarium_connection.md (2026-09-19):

# Подключение монтировки к программе Stellarium (протокол LX200)

🌐 **Русский** | [English](stellarium_connection.en.md)

Для Stellarium используется отдельная прошивка [`src/stellarium_firmware.ino`](../src/stellarium_firmware.ino).
Stellarium видит ESP32 как монтировку **Meade LX200 (compatible)**; связь — по USB (serial, 9600 8N1).
Вся математика (пересчёт углов энкодеров в RA/Dec) и модель привязки считаются на ESP32.
Параметры удобнее всего задавать через веб-интерфейс по Wi-Fi (ESP32 поднимает свою точку
доступа), текстовые команды по serial тоже работают.

## 1. Прошивка

- Arduino IDE → плата **ESP32 Dev Module** → открыть `stellarium_firmware.ino` → загрузить.
- Схема разделов: подойдёт стандартная (по умолчанию) — скетч занимает ~82% её объёма.
  Если планируете доработки, выберите **«Huge APP (3MB No OTA/1MB SPIFFS)»** («Инструменты →
  Partition Scheme») — будет запас. После смены схемы разделов проверьте на странице настроек,
  что сохранённые слоты места и настройки осей на месте.
- USB-порт в прошивке работает на **9600 бод** (на этой скорости его открывает Stellarium),
  поэтому и «Монитор порта» открывайте на 9600.

## 2. Настройка через веб-интерфейс (Wi-Fi)

При включении ESP32 поднимает собственную точку доступа Wi-Fi:

- сеть **`redstar01`**, пароль **`1234567890`**;
- страница настроек: **https://192.168.4.1/** (сертификат самоподписанный)

1. На телефоне или ноутбуке подключитесь к сети `redstar01`. Интернет на этом устройстве
   пропадёт (ESP32 интернет не раздаёт) — это нормально, на время настройки.
2. Откройте в браузере `https://192.168.4.1/`. Браузер один раз предупредит, что
   сертификат самоподписанный: в Chrome — «Дополнительно» → «Перейти», в других браузерах —
   «Принять риск»/«Продолжить». Это безопасно, сертификат вшит в прошивку и действует
   только в этой сети.
3. На странице вверху — живое состояние (время, место, углы энкодеров, RA/Dec), ниже — формы:
   - **Время UTC** — поле для ввода времени в UTC. Кнопка **«Взять время с этого
     устройства»** подставляет в поле текущее время браузера (переведённое в UTC),
     после чего нажмите **«Применить»** — только тогда время попадёт в ESP32;
   - **Место** — **три слота места** (хранятся в памяти ESP32). У каждого слота:
     название (необязательно), широта и долгота (север/восток `+`, юг/запад `-`),
     кнопка **«Взять GPS»** (координаты берутся у браузера — телефон с GPS — и
     подставляются в поля слота; при первом нажатии разрешите доступ к геопозиции),
     кнопка **«Сохранить»** (записать слот в память) и кнопка **«Использовать»**
     (сделать слот текущим местом наблюдения). Текущий, то есть активный, слот
     подсвечен и помечен «используется»; кнопка «Очистить» сбрасывает слот;
    - **Оси** — чекбоксы «Инверсия оси AZM/ALT» (эквивалент `AZDIR -1`/`ALTDIR -1`)
      и нули `AZZERO`/`ALTZERO`; кнопки «AZ = 0 сейчас» и «ALT = 0 сейчас» делают
      текущее положение нулём оси: «ALT = 0 сейчас» нажимайте при горизонтальной трубе,
      «AZ = 0 сейчас» — при трубе, направленной на север (см. §3 «Нули энкодеров»).
      Направления и нули задавайте до привязки: после их изменения точки Sync неверны —
      нажмите `CLEAR` и привяжитесь заново;
   - **Привязка** — таблица сохранённых точек Sync (углы осей, истинные углы,
     невязка) с кнопкой «Удалить» у каждой, кнопка сброса всех точек (`CLEAR`)
     и текстовый `STATUS`.

   Ответы на команды показываются внизу страницы, всё сохраняется в памяти ESP32 так же,
   как при вводе команд по serial.

Wi-Fi и LX200 работают одновременно: Stellarium подключён по USB, а настройки в это же время
задаются со страницы. Wi-Fi-адаптер устройства подключается
только к одной сети, поэтому на время работы со страницей ноутбук будет без интернета
(настройку удобно делать с телефона).

Если включённый Wi-Fi не нужен, его можно отключить: в начале `stellarium_firmware.ino`
замените `#define WEB_UI 1` на `#define WEB_UI 0` и перепрошейте плату.

## 3. Время и место наблюдения (команды serial)

Если веб-интерфейс недоступен, те же параметры задаются текстовыми командами.
Команды вводятся текстом с переводом строки в «Монитор порта» (USB, 9600). Пока с портом
работает Stellarium, команды в него вводить нельзя — вводите команды до подключения
Stellarium (веб-страница по Wi-Fi при этом работает всегда).

| Команда | Пример | Назначение |
|---|---|---|
| `T ГГГГ-ММ-ДД ЧЧ:ММ:СС` | `T 2026-09-17 18:00:00` | время **UTC** |
| `SLOT <n> <широта> <долгота> [название]` | `SLOT 1 55.0583 73.2950 Дача` | сохранить слот места (n = 1..3) |
| `SLOTUSE <n>` | `SLOTUSE 1` | сделать слот текущим местом |
| `SLOTCLEAR <n>` | `SLOTCLEAR 1` | очистить слот |
| `AZDIR 1` / `AZDIR -1` | `AZDIR -1` | направление оси азимута |
| `ALTDIR 1` / `ALTDIR -1` | `ALTDIR 1` | направление оси высоты |
| `AZZERO <град>` | `AZZERO -340` | смещение нуля энкодера азимута |
| `ALTZERO <град>` | `ALTZERO -340` | смещение нуля энкодера высоты |
| `STATUS` | `STATUS` | текущее состояние (в т.ч. список точек привязки) |
| `PTDEL <n>` | `PTDEL 2` | удалить точку привязки с номером n (номера в `STATUS`) |
| `CLEAR` | `CLEAR` | сбросить привязку (точки Sync) |
| `HELP` | `HELP` | список команд |

Место хранится в трёх слотах (команды `SLOT`/`SLOTUSE`/`SLOTCLEAR` или кнопки на
веб-странице), и настройки осей — всё это сохраняется в памяти ESP32 и действует после
перезагрузки: после включения текущим местом сразу становится активный слот.
Время нужно задавать после каждого включения (RTC на плате нет; если команду `T` не задать,
используется время компиляции прошивки как приблизительное).

Пример первичной настройки (ввести по одной строке):

```
T 2026-09-17 18:00:00
SLOT 1 55.0583 73.2950 Дача
SLOTUSE 1
STATUS
```

Широта и долгота должны совпадать с местоположением, выставленным в Stellarium
(окно настроек → «Местоположение»), а время — в UTC.

### Проверка направления осей

`STATUS` (и таблица «Состояние» на веб-странице) показывает для каждой оси три числа.
На примере азимута:

```
Энкодер AZ: raw 7456 (163.80°), после настройки: 163.800°
```

- `raw 7456` — «сырые» шаги энкодера, 0…16383 на полный оборот
  (1 шаг = 360/16384 ≈ 0,022° ≈ 1,3 угловой минуты);
- `(163.80°)` — тот же угол в градусах, ещё без направления и нуля:
  `шаги × 360 / 16384`;
- `после настройки: 163.800°` — угол оси в системе монтировки после `AZDIR`/`AZZERO`:
  `норм(направление × raw° + нуль)`, где азимут нормализуется в 0…360°, а высота — в −180…+180°.

Это ещё **не** реальный азимут и не реальная высота трубы — реальные углы показывает
следующая строка (`Углы монтировки` в `STATUS`, «Монтировка» на веб-странице) уже с
учётом привязки.

Поверните монтировку:

- по азимуту **по часовой стрелке** (вид сверху) — «после настройки» азимута должно расти;
- труба **вверх** — «после настройки» высоты должно расти.

Если растёт в обратную сторону — задайте `AZDIR -1` и/или `ALTDIR -1`.

### Нули энкодеров (AZZERO/ALTZERO)

Энкодер — абсолютный датчик в пределах одного оборота: он всегда выдаёт 0…16383 шагов,
но где у этого оборота «ноль» — зависит только от того, как при сборке поставлен магнит
относительно оси, и с механикой монтировки никак не связано. Нули `AZZERO`/`ALTZERO`
сдвигают шкалу энкодера так, чтобы её ноль оказался в удобном месте; значения хранятся
в памяти ESP32.

**В каком положении трубы выставлять нули:**

| Ось | Положение трубы | Действие | Зачем |
|---|---|---|---|
| Высота (ALT) | труба горизонтально, смотрит на горизонт (проверить уровнем) | кнопка «ALT = 0 сейчас» (или `ALTZERO`) | ход трубы ложится вокруг 0° и целиком остаётся в одной половине шкалы |
| Азимут (AZ) | труба направлена на север (например, на Полярную) | кнопка «AZ = 0 сейчас» (или `AZZERO`) | «после настройки» отсчитывается от севера (удобно читать, на точность не влияет) |

Кнопки учитывают инверсию осей (`AZDIR`/`ALTDIR`) автоматически. Если задаёте команды
вручную, знак зависит от направления: при `ALTDIR 1` это `ALTZERO -<raw°>`, при
`ALTDIR -1` — `ALTZERO +<raw°>` (для азимута так же).

**Почему у высоты это важно, а у азимута — почти нет.** Круговую шкалу нельзя превратить
в число без разрыва: у азимута он в 0°/360°, у высоты — в ±180° (см. «Проверка направления осей»).

- У азимута разрыв безобиден: азимут — окружность, и прошивка всегда сравнивает углы по
  короткой дуге. `AZZERO` нужен в основном для удобства.
- У высоты разрыв опасен: если он попадает внутрь реального хода трубы, «после настройки»
  посреди движения перескакивает на 360° (например, `+179,9°` → `−179,9°`). Точки Sync по
  разные стороны разрыва модель видит как разнесённые на ~360°, и крест визирных нитей
  скачет или уезжает. Обнуление при горизонтальной трубе уводит ход от разрыва на 180°.

Обычно нули можно не трогать: первая же привязка (Sync) вычитает постоянное смещение.
Проверить просто: медленно проведите трубой через весь реальный ход и следите за «после
настройки» высоты — если перескока через ±180° нигде нет, всё в порядке.

Порядок: сначала `AZDIR`/`ALTDIR` и нули, затем Sync. После изменения направления или
нуля старые точки Sync становятся неверными (в них записаны прежние показания осей) —
сделайте `CLEAR` и привяжитесь заново.

Если труба уходит за вертикаль (перевал через зенит или надир), прошивка считает
координаты отражёнными: азимут +180°, высота 180°−высота. Это та же самая точка неба,
поэтому крест визирных нитей продолжает ехать, а не замирает в зените.

### Точность времени и места

Время и место входят в расчёты одинаково — только через звёздное время
`LST = GMST(UTC) + долгота`. Если LST в ESP32 и Stellarium различаются, крест визирных
нитей оказывается повёрнут вокруг оси мира на этот угол: **у Полярной ошибки нет**,
а к небесному экватору она растёт и достигает максимума (внешне это похоже на «крест
не попадает по азимутальной сетке»). 1 секунда времени = 15 угловых секунд неба,
1 минута = 15 дуговых минут, 1 час = 15°; 1 дуговая минута долготы равна 4 секундам
времени. Ошибка широты даёт смещение того же порядка, что и сама ошибка.

| Расхождение времени | Поворот неба | Ошибка у экватора | Ошибка при δ = 45° |
|---|---|---|---|
| 1 с | 15″ | 15″ | 11″ |
| 10 с | 2,5′ | 2,5′ | 1,8′ |
| 30 с | 7,5′ | 7,5′ | 5,3′ |
| 1 мин | 15′ | 15′ | 10,6′ |
| 5 мин | 1,25° | 1,25° | 53′ |
| 1 час | 15° | 15° | 10,6° |

Для визуальных наблюдений держите ошибку наведения не больше ~1/3 поля зрения окуляра.
Отсюда допустимое расхождение времени: обзорный окуляр (поле ~2°) — до 2–3 минут,
25 мм (~1,4°) — до 1,5–2 минут, 10 мм (~0,6°) — до 40 секунд. Практический ориентир —
**не больше 10 секунд**: это ошибка ≤2,5′ у экватора (у Полярной её нет) и меньше одного
шага энкодера (14 бит ≈ 1,3′), точнее выставлять смысла нет.

- **Время** проще всего брать кнопкой «Взять время с этого устройства» (часы телефона
  или ноутбука синхронизированы по NTP), затем «Применить». Если вводите вручную —
  только UTC: ошибка на местный часовой пояс — 15° на каждый час.
- Часы компьютера со Stellarium тоже должны быть синхронизированы (Linux:
  `timedatectl status` должен показывать синхронизацию). Собственный дрейф ESP32 и
  компьютера за ночь — доли секунды, им можно пренебречь.
- Если в Stellarium время сдвинуто вручную или ускорено, ESP32 об этом не знает:
  задайте тот же момент командой `T` (при ускоренном времени совпадения не будет в принципе).
- **Долгота**: GPS с телефона (±10 м) даёт запас в сотни раз; даже ошибка 0,1° (единицы
  километров) даёт ≤6′. Следите только за знаком: восток `+`, запад `-` — перепутанный
  знак разворачивает крест на десятки градусов.
- **Широта**: ошибка даёт примерно такое же смещение по высоте; GPS здесь тоже с запасом,
  а карта с точностью до ~10 км — ≤5′. Не перепутайте широту с долготой местами.

Порядок настройки: сначала время (`T`), активный слот места (`SLOTUSE`) и настройки осей
(`AZDIR`/`ALTDIR`, нули — см. ниже), потом Sync. Точки привязки считаются по текущим
времени, месту и показаниям осей: если исправить их после привязки, модель станет
неверной — сделайте `CLEAR` и привяжитесь заново.

## 4. Подключение по USB

Порт определяется автоматически:

- **Windows**: после установки драйвера CP210x или CH340 (в зависимости от платы) в
  «Диспетчере устройств» появится `COMx`.
- **Linux**: `/dev/ttyUSB0` (или `/dev/ttyACM0`). Пользователь должен быть в группе `dialout`
  (`sudo usermod -aG dialout $USER`, затем перелогиниться).
- **Linux, важно**: имя `/dev/ttyUSBx` не постоянно — после переподключения платы или сбоя
  USB номер может измениться (`ttyUSB0` → `ttyUSB1`), и Stellarium, запомнивший старый путь,
  перестанет подключаться с ошибкой `cannot open serial device`. Указывайте стабильный путь
  из `/dev/serial/by-id/` (он не зависит от порядка перечисления):
  ```
  ls /dev/serial/by-id/
  # usb-Silicon_Labs_CP2102_USB_to_UART_Bridge_Controller_0001-if00-port0
  ```
- **Stellarium из snap** (`stellarium-daily`, имя snap может отличаться): нужно один раз разрешить доступ к USB-serial:
  ```
  sudo snap connect stellarium-daily:raw-usb
  ```

### Настройка телескопа в Stellarium

1. `F2` → плагин **«Управление телескопом»** (Telescope Control) → «Настроить»
   (или `Ctrl+1` — окно «Телескопы»).
2. «Добавить новый телескоп».
3. «Телескоп управляется:» → **«Stellarium, напрямую (через послед. порт или сеть)»**.
4. «Модель устройства:» → **LX200 (compatible)**.
5. «Соединение:» → **«Послед. порт»** (не «Сеть (TCP)»).
6. «Последовательный порт:» → `COMx` / `/dev/ttyUSB0` (Linux: лучше путь из
   `/dev/serial/by-id/`, см. §4).
7. «Равноденствие» → **J2000 (по умолчанию)** — прошивка отдаёт координаты в J2000.
8. «Задержка подключения» — по умолчанию 0.5 с.
9. Сохранить и нажать **«Подключить»**.

После подключения в небе появится крест визирных нитей телескопа. Пока не сделано
ни одного Sync, крест стоит на полюсе мира (рядом с Полярной) и двигается вместе с
ручками монтировки: прошивка считает, что в момент включения труба смотрела на полюс.
Если монтировка выставлена по уровню и при включении труба смотрела на Полярную, можно
наводиться даже без привязки — первый Sync заменяет эту грубую модель точной.

## 5. Привязка к звёздам

Пока нет ни одной точки Sync, прошивка считает, что в момент включения (или после `CLEAR`)
труба смотрела на полюс мира: крест визирных нитей стоит у Полярной и следует за монтировкой.
Первый Sync заменяет эту грубую модель. Удобный порядок: наведите трубу на Полярную и
сделайте первый Sync по ней, затем уточните привязку по 1–2 звёздам в другой части неба.

1. Убедитесь, что время (UTC) и место в ESP32 совпадают с настройками Stellarium
   (см. §3 «Точность времени и места»).
2. Наведите монтировку на яркую звезду и отцентрируйте её в окуляре.
   - Привязку делайте, когда труба **ниже зенита** (не на перевале): модель поправок
     считает высоту от обычного положения оси, и Sync на перевале сдвинет её для всего неба.
3. Выберите эту звезду в Stellarium (клик по звезде).
4. Нажмите **`Ctrl+Shift+1`** — «Синхронизировать телескоп #1 с выбранным объектом»
   (в окне «Навести» это кнопки «Текущий объект» → «Синхронизировать»).
5. Повторите шаги 2–4 для 2–3 звёзд, разнесённых по небу (можно и больше, всего
   хранится до 6 точек).
   - 1 звезда — постоянные смещения по осям;
   - 2 звезды — те же смещения, усреднённые по двум точкам;
   - от 3 звёзд — линейная модель ошибок (МНК по всем сохранённым точкам).
6. Для наведения на объект выберите его в Stellarium и нажмите `Ctrl+1` — крест визирных
   нитей покажет цель, а трубу подводите вручную по разнице положений.
7. Сбросить привязку (например, после переборки монтировки) можно командой `CLEAR`
   по serial или кнопкой на веб-странице. После сброса крест снова отсчитывается
   от полюса, причём полюсом считается текущее положение трубы.

Повторный Sync рядом с уже привязанной звездой (в пределах ~5° по углам осей)
**обновляет** её точку, а не добавляет почти такую же вторую: если после наведения
крест не совпал со звездой, просто наведитесь точнее и нажмите Sync ещё раз — это
безопасно. Когда набрано 6 точек, новый Sync в стороне заменяет самую старую.
Состав точек и невязку (ошибку модели в каждой точке) показывает `STATUS` и таблица
«Привязка» на веб-странице; там же точку можно удалить кнопкой, а по serial —
командой `PTDEL <номер>`.

Совет: после каждого Sync проверяйте точность у этой же звезды — крест визирных нитей
должен совпасть со звездой. Если уехало — нажмите Sync ещё раз.

## 6. Частые проблемы

| Симптом | Причина/решение |
|---|---|
| В Stellarium нет порта в списке | Linux: нет прав (`dialout`), для snap не выполнен `snap connect ...raw-usb`, кабель без данных (charge-only) |
| Порт занят / не подключается | Открыт «Монитор порта» (закройте его) или другой программой |
| После «Отключить» повторно не подключается, в логе `cannot open serial device` | Плата переподключилась под другим именем (`/dev/ttyUSB0` → `/dev/ttyUSB1`) — укажите порт из `/dev/serial/by-id/...` (см. §4) |
| Страница `https://192.168.4.1/` не открывается | Устройство не подключено к сети `redstar01` (Wi-Fi смотрит в другую сеть); проверьте, что залита именно эта прошивка |
| Браузер пишет «Подключение не защищено» / ругается на сертификат | Так и задумано: сертификат самоподписанный и действует только в этой сети. Нажмите «Дополнительно» → «Перейти» (Chrome) или «Принять риск» (другие браузеры) |
| Нет запроса GPS-координат | Разрешите доступ к геопозиции для браузера в настройках телефона; на компьютере без GPS-модуля координаты могут быть определены по Wi-Fi/сети — это неточно |
| Скетч не собирается: «Sketch too big» | Выбрана слишком маленькая схема разделов: возьмите стандартную или «Huge APP (3MB No OTA/1MB SPIFFS)» (см. §1) |
| Крест визирных нитей дёргается и «улетает» | Не выбран слот места (`SLOTUSE`) или не задано время (`T`), либо неверное направление осей (`AZDIR`/`ALTDIR`), либо большие ошибки привязки (см. §3) |
| Крест скачет/уезжает, когда труба проходит определённое место: в `STATUS` «после настройки» высоты перескакивает ≈+180° → −180° | Разрыв шкалы высоты попал внутрь хода трубы: поставьте трубу горизонтально, нажмите «ALT = 0 сейчас» (или задайте `ALTZERO`), затем `CLEAR` и Sync заново (см. §3 «Нули энкодеров») |
| Привязка «сломалась» после смены `AZDIR`/`ALTDIR`/`AZZERO`/`ALTZERO` | Точки Sync хранят прежние показания осей: сделайте `CLEAR` и привяжитесь заново |
| Крест визирных нитей не двигается | Выбран не тот порт; залита прошивка SkySafari (у неё другой протокол); в Stellarium выбран «Сеть (TCP)» вместо «Послед. порт» |
| Большие промахи | Не задано время UTC (`T`), не совпадает место (координаты активного слота), неверные `AZDIR`/`ALTDIR`, мало звёзд привязки или они расположены близко друг к другу |
| Крест повёрнут вокруг Полярной: у полюса совпадает, к экватору сильно уезжает | Разошлось звёздное время: неточное время (`T`) или долгота (активный слот); 1 мин времени = 15′ у экватора (см. §3). Если исправлено после привязки — `CLEAR` и Sync заново |
| Крест смещён по высоте почти одинаково по всему небу | Неверная широта (активный слот) или ошибки привязки |
| Привязка «слетела» после выключения | Так и задумано: точки Sync хранятся только в RAM; слоты места и настройки осей сохраняются |

## 7. Примечания

- Stellarium не передаёт на монтировку ни время, ни координаты места — их надо задать
  на веб-странице или командами (`T`, `SLOT`/`SLOTUSE`).
- Веб-интерфейс живёт только по Wi-Fi: USB-порт ESP32 — это обычный последовательный порт,
  браузер по нему открыть страницу не может.
- Пока нет точек привязки, координаты считаются от полюса мира (см. §5); это не «ошибка»
  и не требует настройки — первый Sync переводит прошивку на обычную модель.
- GPS-координаты берутся с устройства, на котором открыта страница (телефон с GPS), и
  подставляются в поля слота (сохранение — командой `SLOT`): браузеры отдают геолокацию
  только по HTTPS, поэтому страница отдаётся по HTTPS с самоподписанным сертификатом.
  На адрес `http://192.168.4.1/` устройство отвечает редиректом на HTTPS.
- Прошивка не поддерживает TCP-подключение LX200 (хост:порт) — используйте «Послед. порт»
  (USB).
- Рефракция не моделируется; для push-to точности это несущественно.

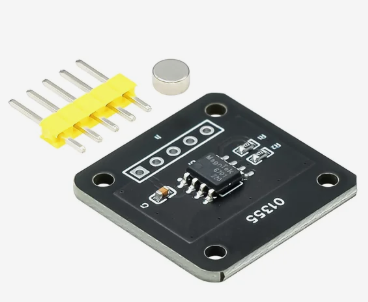
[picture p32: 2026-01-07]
tutorials/img/MT6701.png

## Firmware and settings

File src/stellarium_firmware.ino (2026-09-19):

/*
 * Описание:
 *  Прошивка ESP32 (push-to монтировка sv225) для программы Stellarium.
 *  Протокол Meade LX200 (compatible): USB serial (9600 8N1).
 *  Обе оси (MT6701) пересчитываются в RA/Dec (J2000) на самой ESP32,
 *  привязка к звёздам (Sync) строит модель поправок.
 *
 *  Время и место наблюдения задаются в runtime командами (см. HELP):
 *    T YYYY-MM-DD HH:MM:SS   - время UTC
 *    SLOT <n> <lat> <lon> [название] - сохранить слот места (n = 1..3)
 *    SLOTUSE <n>             - сделать слот текущим местом
 *    SLOTCLEAR <n>           - очистить слот
 *    AZDIR / ALTDIR 1|-1     - направление осей
 *    AZZERO / ALTZERO <°>    - смещение нуля осей
 *    STATUS, CLEAR, HELP
 *
 *  Те же параметры можно задавать с телефона или ноутбука через веб-интерфейс:
 *  ESP32 поднимает точку доступа Wi-Fi (redstar01) и отдаёт страницу настроек
 *  по адресу https://192.168.4.1/ (самоподписанный сертификат) - веб работает
 *  одновременно с LX200 по USB. На странице есть и кнопка взятия
 *  GPS-координат (браузеры отдают их только по HTTPS). Место хранится
 *  в трёх слотах с названиями (NVS), текущее место - активный слот.
 *
 * Автор: Красноперов Павел
 *   https://t.me/redstar01
 *
 * Документация, новые версии программы:
 *   https://github.com/redstar01/sv225_push_to_mount
 */

#include <Arduino.h>
#include <Wire.h>
#include <Preferences.h>

// ----------------------------- настройки -----------------------------

#define WEB_UI 1  // веб-настройка по Wi-Fi (0 - отключить Wi-Fi вместе со страницей)

#if WEB_UI
#include <WiFi.h>
#include <esp_https_server.h>
#endif

static const uint32_t SERIAL_BAUD      = 9600;              // Stellarium открывает serial на 9600 8N1
static const uint16_t ENCODER_STEPS    = 16384;             // MT6701: 14 бит
static const uint32_t ENCODER_READ_MS  = 50;
static const uint8_t  MAX_ALIGN_POINTS = 6;                 // 1 - смещения, 2 - среднее, от 3 - линейная модель (МНК)
static const double   PT_REPLACE_DEG   = 2.0;               // Sync рядом с точкой - обновление, а не дубликат
static const uint8_t  MAX_SLOTS        = 3;                 // слоты мест наблюдения (NVS)
static const uint8_t  SLOT_NAME_BYTES  = 48;                // имя слота (UTF-8, включая NUL)
static const uint8_t  CMD_BUF_SIZE     = 192;               // имя слота в URL-кодировке
static const uint32_t TEXT_CMD_TIMEOUT_MS = 500;            // сброс недополученной текстовой строки

#if WEB_UI
static const char     AP_SSID[]        = "redstar01";       // точка доступа для страницы настроек
static const char     AP_PASS[]        = "1234567890";
static const uint16_t WEB_PORT         = 443;               // HTTPS; на 80 порту - редирект
#endif

static const double DEG2RAD = 0.017453292519943295;
static const double RAD2DEG = 57.29577951308232;

// ----------------------------- состояние -----------------------------

struct Link {
  Stream* io;
  char    buf[CMD_BUF_SIZE];
  uint8_t len;
  uint8_t mode;  // 0 - ожидание, 1 - команда LX200 (до '#'), 2 - текстовая команда (до перевода строки)
  uint32_t lastMs;
};

struct AlignPoint {
  double rawAz, rawAlt;    // углы осей (после AZDIR/ALTDIR/AZZERO/ALTZERO)
  double trueAz, trueAlt;  // истинные углы, посчитанные по звезде
};

static Link        g_links[1];
static Preferences g_prefs;

// места наблюдения: три слота с названиями (NVS); текущее место - активный слот
struct SiteSlot {
  bool   set;
  char   name[SLOT_NAME_BYTES];
  double lat, lon;
};

static SiteSlot g_slots[MAX_SLOTS];
static int8_t   g_activeSlot = -1;  // -1 - место не задано

// координаты активного слота (для расчётов)
static double g_latDeg = 0.0;
static double g_lonDeg = 0.0;

// ориентация энкодеров (AZDIR/ALTDIR/AZZERO/ALTZERO, хранится в NVS)
static int8_t g_azDir = 1;
static int8_t g_altDir = 1;
static double g_azZeroDeg = 0.0;
static double g_altZeroDeg = 0.0;

// время UTC
static time_t   g_utcEpoch = 0;
static uint32_t g_utcAtMs = 0;
static bool     g_timeSet = false;

// показания энкодеров
static int    g_rawAz = 0;
static int    g_rawAlt = 0;
static double g_encAz = 0.0;
static double g_encAlt = 0.0;

// «старт от полюса»: пока нет точек привязки, считаем, что в момент включения
// (или после CLEAR) труба смотрела на полюс мира - крест в Stellarium сразу
// у полюса (на Полярной) и далее едет за монтировкой; первый Sync заменяет
// эту грубую модель.
static double g_polarAz = 0.0;   // g_encAz в момент старта
static double g_polarAlt = 0.0;  // g_encAlt в момент старта

// цель :Sr/:Sd (J2000)
static double g_targetRa = 0.0;
static double g_targetDec = 0.0;
static bool   g_targetRaValid = false;
static bool   g_targetDecValid = false;

// модель привязки
static AlignPoint g_pts[MAX_ALIGN_POINTS];
static uint8_t    g_nPts = 0;

struct Model {
  uint8_t n;
  bool    affine;
  double  refAz, refAlt;       // опорная точка (первая)
  double  cAz0, cAz1, cAz2;    // поправка азимута: e = c0 + c1*du + c2*dv
  double  cAlt0, cAlt1, cAlt2; // поправка высоты
};

static Model g_model;

// прототипы
static void readEncoders();
static void saveConfig();
static void saveSlotData(uint8_t i);
static void selectSlot(uint8_t i);
static void clearSlotData(uint8_t i);
static void currentRaDec(double& raJ2000, double& decJ2000);
static void formatRa(double raRad, char* out);
static void formatDec(double decRad, char* out);

// --------------------------- утилиты углов ---------------------------

static inline double clampd(double v, double lo, double hi)
{
  return v < lo ? lo : (v > hi ? hi : v);
}

static inline double norm360(double deg)
{
  deg = fmod(deg, 360.0);
  if (deg < 0.0) deg += 360.0;
  return deg;
}

static inline double norm180(double deg)
{
  deg = norm360(deg);
  if (deg > 180.0) deg -= 360.0;
  return deg;
}

static inline double normRad(double rad)
{
  rad = fmod(rad, 2.0 * M_PI);
  if (rad < 0.0) rad += 2.0 * M_PI;
  return rad;
}

// ------------------------------- время -------------------------------

static long long daysFromCivil(int y, int m, int d)
{
  y -= (m <= 2);
  const long long era = (y >= 0 ? y : y - 399) / 400;
  const unsigned  yoe = (unsigned)(y - era * 400);
  const unsigned  doy = (unsigned)((153 * (m + (m > 2 ? -3 : 9)) + 2) / 5 + d - 1);
  const unsigned  doe = yoe * 365 + yoe / 4 - yoe / 100 + doy;
  return era * 146097 + (long long)doe - 719468;
}

static void civilFromDays(long long z, int& y, int& m, int& d)
{
  z += 719468;
  const long long era = (z >= 0 ? z : z - 146096) / 146097;
  const unsigned  doe = (unsigned)(z - era * 146097);
  const unsigned  yoe = (doe - doe / 1460 + doe / 36524 - doe / 146096) / 365;
  const long long yy  = (long long)yoe + era * 400;
  const unsigned  doy = doe - (365 * yoe + yoe / 4 - yoe / 100);
  const unsigned  mp  = (5 * doy + 2) / 153;
  d = (int)(doy - (153 * mp + 2) / 5 + 1);
  m = (int)(mp < 10 ? mp + 3 : mp - 9);
  y = (int)(yy + (m <= 2));
}

static void setUtc(time_t t)
{
  g_utcEpoch = t;
  g_utcAtMs = millis();
}

static time_t utcNow()
{
  return g_utcEpoch + (time_t)((millis() - g_utcAtMs) / 1000);
}

static void formatTimeUtc(char* out, size_t n)
{
  time_t t = utcNow();
  long long days = (long long)t / 86400;
  long rem = (long)t % 86400;
  if (rem < 0) { rem += 86400; days--; }
  int y, m, d;
  civilFromDays(days, y, m, d);
  snprintf(out, n, "%04d-%02d-%02d %02d:%02d:%02d",
           y, m, d, (int)(rem / 3600), (int)((rem / 60) % 60), (int)(rem % 60));
}

// запасное время - момент компиляции (считаем его UTC, точность не гарантируется)
static void loadCompileTime()
{
  static const char months[] = "JanFebMarAprMayJunJulAugSepOctNovDec";
  char mon[4] = {0};
  int day = 0, year = 0, h = 0, mi = 0, s = 0;
  if (sscanf(__DATE__, "%3s %d %d", mon, &day, &year) == 3 &&
      sscanf(__TIME__, "%d:%d:%d", &h, &mi, &s) == 3) {
    int m = 0;
    for (int i = 0; i < 12; i++) {
      if (!strncmp(mon, months + i * 3, 3)) { m = i + 1; break; }
    }
    if (m > 0) {
      setUtc(daysFromCivil(year, m, day) * 86400 + h * 3600 + mi * 60 + s);
      return;
    }
  }
  setUtc(daysFromCivil(2000, 1, 1) * 86400);
}

// ----------------------------- энкодеры ------------------------------

static int readAngle(TwoWire& wire)
{
  wire.beginTransmission(0b0000110);
  wire.write(0x03);
  wire.endTransmission(false);
  wire.requestFrom((int)0b0000110, 2);
  if (wire.available() < 2) {
    return -1;
  }
  int angleH = wire.read();
  int angleL = wire.read();
  return (angleH << 6) | (angleL >> 2);
}

static void readEncoders()
{
  int rawAz = readAngle(Wire1);
  if (rawAz >= 0) g_rawAz = rawAz;
  int rawAlt = readAngle(Wire);
  if (rawAlt >= 0) g_rawAlt = rawAlt;

  double azDeg  = (double)g_rawAz * 360.0 / ENCODER_STEPS;
  double altDeg = (double)g_rawAlt * 360.0 / ENCODER_STEPS;
  g_encAz  = norm360((double)g_azDir * azDeg + g_azZeroDeg);
  g_encAlt = norm180((double)g_altDir * altDeg + g_altZeroDeg);
}

// запомнить текущее положение как «труба смотрит на полюс мира»
static void setPolarStart()
{
  g_polarAz = g_encAz;
  g_polarAlt = g_encAlt;
}

// ------------------------------ модель -------------------------------

static bool solve3(const double m[3][3], const double b[3], double x[3])
{
  double a[3][4];
  for (int i = 0; i < 3; i++) {
    for (int j = 0; j < 3; j++) a[i][j] = m[i][j];
    a[i][3] = b[i];
  }
  for (int col = 0; col < 3; col++) {
    int piv = col;
    for (int r = col + 1; r < 3; r++) {
      if (fabs(a[r][col]) > fabs(a[piv][col])) piv = r;
    }
    if (fabs(a[piv][col]) < 1e-9) return false;
    if (piv != col) {
      for (int j = 0; j < 4; j++) {
        double t = a[col][j]; a[col][j] = a[piv][j]; a[piv][j] = t;
      }
    }
    for (int r = 0; r < 3; r++) {
      if (r == col) continue;
      double f = a[r][col] / a[col][col];
      for (int j = col; j < 4; j++) a[r][j] -= f * a[col][j];
    }
  }
  for (int i = 0; i < 3; i++) x[i] = a[i][3] / a[i][i];
  return true;
}

static void rebuildModel()
{
  g_model.n = g_nPts;
  g_model.affine = false;
  if (g_nPts == 0) return;

  g_model.refAz  = g_pts[0].rawAz;
  g_model.refAlt = g_pts[0].rawAlt;

  double eAz[MAX_ALIGN_POINTS], eAlt[MAX_ALIGN_POINTS];
  double du[MAX_ALIGN_POINTS], dv[MAX_ALIGN_POINTS];
  for (uint8_t i = 0; i < g_nPts; i++) {
    du[i]   = norm180(g_pts[i].rawAz - g_model.refAz);
    dv[i]   = g_pts[i].rawAlt - g_model.refAlt;
    eAz[i]  = norm180(g_pts[i].trueAz - g_pts[i].rawAz);
    eAlt[i] = g_pts[i].trueAlt - g_pts[i].rawAlt;
  }

  if (g_nPts == 1) {
    g_model.cAz0  = eAz[0];
    g_model.cAlt0 = eAlt[0];
    return;
  }

  if (g_nPts == 2) {
    // для азимута - круговое среднее (учитывает переход через 360°)
    g_model.cAz0 = atan2((sin(eAz[0] * DEG2RAD) + sin(eAz[1] * DEG2RAD)) / 2.0,
                         (cos(eAz[0] * DEG2RAD) + cos(eAz[1] * DEG2RAD)) / 2.0) * RAD2DEG;
    g_model.cAlt0 = 0.5 * (eAlt[0] + eAlt[1]);
    return;
  }

  // от 3 точек: линейная модель e = c0 + c1*du + c2*dv (МНК по всем точкам)
  double m[3][3] = {{0}};
  double bAz[3] = {0}, bAlt[3] = {0};
  for (uint8_t i = 0; i < g_nPts; i++) {
    double u = du[i], v = dv[i];
    m[0][0] += 1.0; m[0][1] += u; m[0][2] += v;
    m[1][1] += u * u; m[1][2] += u * v; m[2][2] += v * v;
    bAz[0]  += eAz[i];  bAz[1]  += eAz[i] * u;  bAz[2]  += eAz[i] * v;
    bAlt[0] += eAlt[i]; bAlt[1] += eAlt[i] * u; bAlt[2] += eAlt[i] * v;
  }
  m[1][0] = m[0][1]; m[2][0] = m[0][2]; m[2][1] = m[1][2];

  double cAz[3], cAlt[3];
  if (solve3(m, bAz, cAz) && solve3(m, bAlt, cAlt)) {
    g_model.affine = true;
    g_model.cAz0 = cAz[0];  g_model.cAz1 = cAz[1];  g_model.cAz2 = cAz[2];
    g_model.cAlt0 = cAlt[0]; g_model.cAlt1 = cAlt[1]; g_model.cAlt2 = cAlt[2];
  } else {
    double sumSin = 0.0, sumCos = 0.0, sumAlt = 0.0;
    for (uint8_t i = 0; i < g_nPts; i++) {
      sumSin += sin(eAz[i] * DEG2RAD);
      sumCos += cos(eAz[i] * DEG2RAD);
      sumAlt += eAlt[i];
    }
    g_model.cAz0  = atan2(sumSin / g_nPts, sumCos / g_nPts) * RAD2DEG;
    g_model.cAlt0 = sumAlt / g_nPts;
  }
}

static void addAlignPoint(double trueAz, double trueAlt, double rawAz, double rawAlt)
{
  // Повторная привязка рядом с уже сохранённой точкой обновляет её, а не
  // добавляет почти такой же дубликат: иначе набор забьётся точками в одной
  // области неба, а линейная модель станет вырожденной.
  int8_t nearIdx = -1;
  double best = PT_REPLACE_DEG;
  for (uint8_t i = 0; i < g_nPts; i++) {
    double dAz  = norm180(rawAz - g_pts[i].rawAz);
    double dAlt = rawAlt - g_pts[i].rawAlt;
    double d    = sqrt(dAz * dAz + dAlt * dAlt);
    if (d < best) { best = d; nearIdx = (int8_t)i; }
  }

  if (nearIdx >= 0) {
    g_pts[nearIdx].rawAz   = rawAz;
    g_pts[nearIdx].rawAlt  = rawAlt;
    g_pts[nearIdx].trueAz  = trueAz;
    g_pts[nearIdx].trueAlt = trueAlt;
  } else {
    if (g_nPts >= MAX_ALIGN_POINTS) {
      for (uint8_t i = 1; i < MAX_ALIGN_POINTS; i++) g_pts[i - 1] = g_pts[i];
      g_nPts = MAX_ALIGN_POINTS - 1;
    }
    g_pts[g_nPts].rawAz   = rawAz;
    g_pts[g_nPts].rawAlt  = rawAlt;
    g_pts[g_nPts].trueAz  = trueAz;
    g_pts[g_nPts].trueAlt = trueAlt;
    g_nPts++;
  }
  rebuildModel();
}

static void removeAlignPoint(uint8_t i)
{
  if (i >= g_nPts) return;
  for (uint8_t k = i + 1; k < g_nPts; k++) g_pts[k - 1] = g_pts[k];
  g_nPts--;
  rebuildModel();
}

// поправки модели для углов осей (без сворачивания через зенит/надир):
// используются и в applyModel(), и для невязок точек привязки
static void modelErrors(double rawAz, double rawAlt, double& eAz, double& eAlt)
{
  eAz = 0.0; eAlt = 0.0;
  if (g_model.n == 0) {
    // нет точек привязки: отсчёт от полюса мира (AZ = 0°, ALT = широта места)
    eAz  = norm180(-g_polarAz);
    eAlt = g_latDeg - g_polarAlt;
  } else if (g_model.n == 1) {
    eAz = g_model.cAz0;
    eAlt = g_model.cAlt0;
  } else if (g_model.affine) {
    double u = norm180(rawAz - g_model.refAz);
    double v = rawAlt - g_model.refAlt;
    eAz  = g_model.cAz0 + g_model.cAz1 * u + g_model.cAz2 * v;
    eAlt = g_model.cAlt0 + g_model.cAlt1 * u + g_model.cAlt2 * v;
  } else {
    eAz = g_model.cAz0;
    eAlt = g_model.cAlt0;
  }
}

// невязка точки привязки: насколько модель ошибается в самой точке, градусы
static void pointResidualDeg(uint8_t i, double& errAz, double& errAlt)
{
  double eAz, eAlt;
  modelErrors(g_pts[i].rawAz, g_pts[i].rawAlt, eAz, eAlt);
  errAz  = norm180(g_pts[i].trueAz - norm360(g_pts[i].rawAz + eAz));
  errAlt = g_pts[i].trueAlt - (g_pts[i].rawAlt + eAlt);
}

static void applyModel(double rawAz, double rawAlt, double& azOut, double& altOut)
{
  double eAz, eAlt;
  modelErrors(rawAz, rawAlt, eAz, eAlt);
  azOut  = norm360(rawAz + eAz);
  altOut = rawAlt + eAlt;

  // Перевал через зенит/надир: ось высоты может уйти за ±90°, но труба смотрит
  // в ту же точку неба, что (азимут+180°, 180°−высота). Обрезать высоту на ±90°
  // нельзя: в зените RA/Dec вырождаются, и крест замирает - перестаёт
  // реагировать на вращение обеих осей, пока монтировку не вернут обратно.
  if (altOut > 90.0) {
    altOut = 180.0 - altOut;
    azOut  = norm360(azOut + 180.0);
  } else if (altOut < -90.0) {
    altOut = -180.0 - altOut;
    azOut  = norm360(azOut + 180.0);
  }
}

// ------------------------- астрономия/позиция -------------------------

static double julianCenturies(time_t t)
{
  double jd = 2440587.5 + (double)t / 86400.0;
  return (jd - 2451545.0) / 36525.0;
}

static double gmstRad(time_t t)
{
  double jd = 2440587.5 + (double)t / 86400.0;
  double d = jd - 2451545.0;
  double T = d / 36525.0;
  double deg = 280.46061837 + 360.98564736629 * d + 0.000387933 * T * T - T * T * T / 38710000.0;
  return norm360(deg) * DEG2RAD;
}

static void precessEquatorial(double& ra, double& dec, double T, bool inverse = false)
{
  const double arcsec = DEG2RAD / 3600.0;
  double zeta  = (2306.2181 + 0.30188 * T + 0.017998 * T * T) * T * arcsec;
  double z     = (2306.2181 + 1.09468 * T + 0.018203 * T * T) * T * arcsec;
  double theta = (2004.3109 - 0.42665 * T - 0.041833 * T * T) * T * arcsec;

  double a, b, c;
  if (inverse) {
    a = cos(dec) * sin(ra - z);
    b = cos(theta) * cos(dec) * cos(ra - z) + sin(theta) * sin(dec);
    c = -sin(theta) * cos(dec) * cos(ra - z) + cos(theta) * sin(dec);
    ra  = normRad(atan2(a, b) - zeta);
  } else {
    a = cos(dec) * sin(ra + zeta);
    b = cos(theta) * cos(dec) * cos(ra + zeta) - sin(theta) * sin(dec);
    c = sin(theta) * cos(dec) * cos(ra + zeta) + cos(theta) * sin(dec);
    ra  = normRad(atan2(a, b) + z);
  }
  dec = asin(clampd(c, -1.0, 1.0));
}

static void raDecToAltAz(double ra, double dec, double lat, double lst,
                         double& alt, double& az)
{
  double H = lst - ra;
  double sinAlt = sin(lat) * sin(dec) + cos(lat) * cos(dec) * cos(H);
  alt = asin(clampd(sinAlt, -1.0, 1.0));
  az  = atan2(-cos(dec) * sin(H), sin(dec) * cos(lat) - cos(dec) * sin(lat) * cos(H));
  az  = normRad(az);
}

static void altAzToRaDec(double alt, double az, double lat, double lst,
                         double& ra, double& dec)
{
  double sinDec = sin(lat) * sin(alt) + cos(lat) * cos(alt) * cos(az);
  dec = asin(clampd(sinDec, -1.0, 1.0));
  double H = atan2(-sin(az) * cos(alt), cos(lat) * sin(alt) - sin(lat) * cos(alt) * cos(az));
  ra = normRad(lst - H);
}

// текущая позиция монтировки в J2000 (радианы)
static void currentRaDec(double& raJ2000, double& decJ2000)
{
  time_t t = utcNow();
  double T = julianCenturies(t);
  double lst = gmstRad(t) + g_lonDeg * DEG2RAD;
  double az, alt;
  applyModel(g_encAz, g_encAlt, az, alt);
  double ra, dec;
  altAzToRaDec(alt * DEG2RAD, az * DEG2RAD, g_latDeg * DEG2RAD, lst, ra, dec);
  precessEquatorial(ra, dec, T, true);  // из даты в J2000
  raJ2000 = ra;
  decJ2000 = dec;
}

// --------------------------- форматирование ---------------------------

static void formatRa(double raRad, char* out)
{
  double hours = norm360(raRad * RAD2DEG) / 15.0;
  long total = lround(hours * 3600.0) % 86400;
  if (total < 0) total += 86400;
  sprintf(out, "%02d:%02d:%02d", (int)(total / 3600), (int)((total / 60) % 60), (int)(total % 60));
}

static void formatDec(double decRad, char* out)
{
  long signedTotal = lround(decRad * RAD2DEG * 3600.0);
  char sign = (signedTotal < 0) ? '-' : '+';
  long total = labs(signedTotal);
  sprintf(out, "%c%02d%c%02d:%02d", sign, (int)(total / 3600), (char)0xDF,
          (int)((total / 60) % 60), (int)(total % 60));
}

// ------------------------------ привязка -----------------------------

static void doSync()
{
  if (!g_targetRaValid || !g_targetDecValid) return;

  time_t t = utcNow();
  double T = julianCenturies(t);
  double lst = gmstRad(t) + g_lonDeg * DEG2RAD;

  double ra = g_targetRa, dec = g_targetDec;
  precessEquatorial(ra, dec, T);  // J2000 -> дата

  double az, alt;
  raDecToAltAz(ra, dec, g_latDeg * DEG2RAD, lst, alt, az);
  addAlignPoint(norm360(az * RAD2DEG), alt * RAD2DEG, g_encAz, g_encAlt);
}

// --------------------------- команды LX200 ---------------------------

static bool parseSetRa(const char* s)
{
  int h, m, sec;
  if (sscanf(s, "%d:%d:%d", &h, &m, &sec) != 3) return false;
  if (h < 0 || h > 23 || m < 0 || m > 59 || sec < 0 || sec > 59) return false;
  g_targetRa = (h + m / 60.0 + sec / 3600.0) * 15.0 * DEG2RAD;
  g_targetRaValid = true;
  return true;
}

static bool parseSetDec(const char* s)
{
  const char* p = s;
  int sign = 1;
  if (*p == '+') p++;
  else if (*p == '-') { sign = -1; p++; }
  else return false;

  if (!isdigit((unsigned char)*p)) return false;
  int d = 0;
  while (isdigit((unsigned char)*p)) { d = d * 10 + (*p - '0'); p++; }

  if (*p != '*' && (uint8_t)*p != 0xDF) return false;
  p++;

  if (!isdigit((unsigned char)*p)) return false;
  int m = 0;
  while (isdigit((unsigned char)*p)) { m = m * 10 + (*p - '0'); p++; }

  int sec = 0;
  if (*p == ':' || *p == '\'') {
    p++;
    if (!isdigit((unsigned char)*p)) return false;
    while (isdigit((unsigned char)*p)) { sec = sec * 10 + (*p - '0'); p++; }
  }
  if (*p != 0) return false;
  if (d > 90 || m > 59 || sec > 59) return false;

  double deg = d + m / 60.0 + sec / 3600.0;
  if (deg > 90.0) return false;
  g_targetDec = sign * deg * DEG2RAD;
  g_targetDecValid = true;
  return true;
}

static void handleLx200(Link& l, const char* cmd)
{
  if (!strcmp(cmd, ":GR")) {
    double ra, dec;
    currentRaDec(ra, dec);
    char b[16];
    formatRa(ra, b);
    l.io->print(b);
    l.io->print('#');
  } else if (!strcmp(cmd, ":GD")) {
    double ra, dec;
    currentRaDec(ra, dec);
    char b[16];
    formatDec(dec, b);
    l.io->print(b);
    l.io->print('#');
  } else if (!strncmp(cmd, ":Sr", 3)) {
    l.io->print(parseSetRa(cmd + 3) ? '1' : '0');
  } else if (!strncmp(cmd, ":Sd", 3)) {
    l.io->print(parseSetDec(cmd + 3) ? '1' : '0');
  } else if (!strcmp(cmd, ":CM")) {
    doSync();
    l.io->print('0');  // принимается и старыми, и новыми версиями Stellarium
  } else if (!strcmp(cmd, ":MS")) {
    l.io->print('0');  // push-to: наведение выполняет наблюдатель
  } else if (!strcmp(cmd, ":Q") || !strcmp(cmd, ":U")) {
    // нет ответа
  } else if (!strcmp(cmd, ":GVP")) {
    l.io->print("SV225 PushTo#");
  }
}

// ------------------------- текстовые команды -------------------------
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
void loop()
{
  static uint32_t lastRead = 0;
  uint32_t now = millis();
  if (now - lastRead >= ENCODER_READ_MS) {
    lastRead = now;
    readEncoders();
  }
  serviceLinks();
}

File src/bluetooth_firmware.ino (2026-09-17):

/*
 * Описание:
 *  Прошивка esp32 для передачи значений энкодеров (MT6701) астро-монтировок для работы в Sky Safari
 *
 * Автор: Красноперов Павел
 *   https://t.me/redstar01
 *
 * Документация, новые версии программы:
 *   https://github.com/redstar01/sv225_push_to_mount
 */

#include "BluetoothSerial.h"
#if !defined(CONFIG_BT_ENABLED) || !defined(CONFIG_BLUEDROID_ENABLED)
#error Bluetooth is not enabled!
#endif

#include <Wire.h>

BluetoothSerial client;

void setup()
{
  delay(1000);

  client.begin("ESP32test");

  Serial.begin(115200);

  Wire.begin();
  Wire.setClock(400000);

  Wire1.begin(18,19);
  Wire1.setClock(400000);
}

void loop() {
  int azAngle = readAngle(Wire1);
  int altAngle = readAngle(Wire);

  String logMsg;
  logMsg += "азимут: ";
  logMsg += azAngle;
  logMsg += " ### ";
  logMsg += "высота: ";
  logMsg += altAngle;
  logMsg += "\n";

  Serial.print(logMsg);

  if (client.available() > 0) {
    int request = client.read();
    if (request == 81) {
      printEncoderValue(azAngle);
      client.print("\t");
      printEncoderValue(altAngle);
      client.print("\r");
    }
  }

  delay(200);
}

int readAngle(TwoWire& wire)
{
    uint8_t data[2];
    wire.beginTransmission(0b0000110);
    wire.write(0x03);
    wire.endTransmission(false);
    wire.requestFrom((int)0b0000110, 2);
    if (wire.available() < 2)
    {
        return -1;
    }
    int angle_h = wire.read();
    int angle_l = wire.read();

    return (angle_h << 6) | (angle_l >> 2);
}

void printEncoderValue(long val)
{
  if (val < 10)
    client.print("0000");
  else if (val < 100)
    client.print("000");
  else if (val < 1000)
    client.print("00");
  else if (val < 10000)
    client.print("0");

  client.print(val);
}

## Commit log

2026-01-07 feat: first steps
    [alt_spacer.stl, azm_spacer.stl.stl, body-top.stl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]
2026-01-07 feat: upd 2
    [alt_spacer.stl, azm_spacer.stl.stl, magnet_holder_big_6mm.stl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]
2026-09-19 feat: Stellarium connector
